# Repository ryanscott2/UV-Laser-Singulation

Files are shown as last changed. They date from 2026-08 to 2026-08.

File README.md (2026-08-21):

# UV Laser Singulation

Geometry preparation, stage control, and WinLase automation for four-field
singulation of a 100 mm silicon wafer on a UV galvo system.

Singulation workflow

The laser field remains fixed. A Prior OptiScan III stage moves an edge-datum
wafer jig through four taught positions (`P1`–`P4`), while each DXF is translated
so its field center is at the drawing origin. The result is a repeatable pipeline
from wafer-scale cut geometry to four field-centered WinLase jobs.

> [!CAUTION]
> This repository contains machine-specific geometry, calibration assumptions,
> motion limits, and laser-profile gates. It is not a transferable process recipe.
> UV radiation is invisible; use wavelength- and power-rated eyewear, the
> facility enclosure and interlocks, appropriate extraction for silicon debris,
> and the hardware emergency stop. Prove motion, placement, focus, and process
> settings on sacrificial material before an armed run.

## What the repository does

1. Generates or accepts wafer-centered DXF/GDS/OAS cut geometry.
2. Optionally separates a combined cut layer into horizontal and vertical passes.
3. Clips the design into four station jobs, translates each job to field origin,
   and writes manifests and build logs.
4. Reconstructs the masters from the emitted jobs and checks field placement.
5. Builds one WinLase job per station and runs the `P1 -> P2 -> P3 -> P4`
   stage/mark sequence.
6. Provides Fusion generators and exports for the current edge-datum wafer jig.

### Current geometry defaults

| Setting | Value |
| --- | ---: |
| Wafer | 100 mm |
| Qualified galvo field | 54 × 54 mm |
| Usable central field | 60 × 60 mm |
| Field centers in wafer coordinates | X,Y = ±25.4 mm |
| Split mode | `partition` |
| Total stitch overlap | 400 µm |
| Maximum cut-path width | 50 µm |
| Global placement offset | 0 µm, X and Y |

The stitch and field settings above are the defaults in
[`slicing/split_klayout.py`](slicing/split_klayout.py). They can be overridden by
the build tools, and every emitted set records the effective values.

## Requirements

| Environment | Requirements |
| --- | --- |
| Design/prep PC | Python 3.11+ and `klayout`; `PySide6` for the desktop slicer |
| Laser PC | Windows, Python 3.8+, WinLase Professional, `pywin32`, and either `pyserial` or the pywin32 serial backend |
| Jig regeneration | Autodesk Fusion with its Python API |

Install the prep dependencies:

```bash
pip install klayout PySide6
```

The command-line builders and validators need only `klayout`.

## Quick start: prepare and validate a set

From the repository root:

```bash
python slicing/build_pin_grid_set.py
python slicing/validate_pin_grid_set.py
```

The default build consumes the paired masters in
`dxf/100mm_10x30mm_Masters/` and writes a four-station set under
`output/DXFs/`. Each station folder contains one DXF per pass angle; the set
also contains a position manifest, split logs, and validation output.

For a design whose cut orientations share one layer:

```bash
python slicing/build_pin_grid_set.py \
  --combined wafer.gds \
  --cut-layer 7 \
  --edge-bead 2
```

Useful build controls include `--rotation`, `--jig-flat`, `--cut-width`,
`--width-mode`, `--stitch`, per-station `--offset`, independent X/Y window
centers, and `--clip-mode`. See the complete interface with:

```bash
python slicing/build_pin_grid_set.py --help
```

### Interactive slicer

```bash
python slicing/slicer_app.py
```

The PySide6/QML app previews the wafer, source layers, four-window or center-pass
clipping, cut width, offsets, and edge bead before writing the set. The same
workflow is available from the CLI wrapper:

```bash
python slicing/run_splitter.py --input wafer.dxf --list-layers
```

## Run on the laser PC

Transfer the validated set to the offline machine, then work through dry-run and
pre-flight modes before arming:

```bash
# Parse the set without WinLase, then verify the first job in memory.
python laser-pc/winlase_build_jobs.py output/DXFs/<set> --dry-run
python laser-pc/winlase_build_jobs.py output/DXFs/<set> --verify

# Build all four .wlj files. Close the WinLase GUI first.
python laser-pc/winlase_build_jobs.py output/DXFs/<set>

# Teach P1-P4 once for the current jig/datum, then inspect the run plan.
python laser-pc/optiscan.py jog
python laser-pc/dice_wafer.py output/DXFs/<set> --list

# Real stage motion, simulated marking.
python laser-pc/dice_wafer.py output/DXFs/<set>

# Live laser run.
python laser-pc/dice_wafer.py output/DXFs/<set> --arm
```

`dice_wafer.py` defaults to simulated marking but still moves the real stage. An
armed run adds typed confirmation and a countdown, checks all taught positions
against the current asymmetric stage envelope, verifies the laser profile before
any motion and again at mark time, and supports controlled stop flags. A controlled
stop is not an emergency stop.

The current job builder writes a 100 mm/s mark speed and requires the configured
WinLase profile to read back at 100% power and 30 kHz. The default run count is 175
passes unless overridden by `laser-pc/dice_passes.csv` or `--passes`. These are
rig-specific values recorded by the code, not recommendations for another laser.

For the Tk launcher, double-click [`laser-pc/run_ui.bat`](laser-pc/run_ui.bat).
Detailed machine setup and failure handling are in
[`laser-pc/WINLASE_AUTOMATION_README.md`](laser-pc/WINLASE_AUTOMATION_README.md).

## Coordinate contract

- Source geometry is wafer-centered.
- `P1`–`P4` identify stage/jig stations, not wafer quadrants.
- Each output is translated so its laser-field center lands at `(0, 0)`.
- WinLase auto-centering and fit-to-field scaling must remain off.
- The current edge-datum jig stays seated; the stage performs the indexing.
- Coarse placement lives in the taught stage positions. Splitter global and
  per-station offsets default to zero.

The validator translates every station job back into wafer coordinates, unions the
result, and requires zero XOR area against the source master. It also checks that
the emitted geometry fits the usable field around the origin and exits non-zero on
failure.

## Repository layout

| Path | Purpose |
| --- | --- |
| [`slicing/`](slicing) | KLayout generators, splitters, validators, CLI tools, and PySide6/QML preview |
| [`laser-pc/`](laser-pc) | OptiScan driver, WinLase job builder, sequenced dicer, and Tk launcher |
| [`fusion/`](fusion) | Edge-datum jig generators plus CAD/STL exports |
| [`dxf/`](dxf) | Source drawings and generated wafer masters |
| [`output/`](output) | Generated and validated job sets |
| [`docs/figures/`](docs/figures) | Documentation figures |

## Documentation

- [`DOCUMENTATION.md`](DOCUMENTATION.md) — coordinate frames, labeling,
  splitter guarantees, import settings, and jig details
- [`OPERATING_PROCEDURE.md`](OPERATING_PROCEDURE.md) — operator sequence
- [`CALIBRATION_AND_SLIDING_NEST_NOTES.md`](CALIBRATION_AND_SLIDING_NEST_NOTES.md)
  — measurement history and design decisions
- [`slicing/KLayoutFourWindowSplitter_README.md`](slicing/KLayoutFourWindowSplitter_README.md)
  — splitter configuration and output contract
- [`slicing/CenterPassWorkflow_README.md`](slicing/CenterPassWorkflow_README.md)
  — centered scoring workflow

## License

No license is granted. The repository is published for reference; all rights are
reserved.

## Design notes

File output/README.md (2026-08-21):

# Generated laser job sets

Each folder under `DXFs/` is one complete, validated set of exposure files. The
**current** sets are the dated N-angle sets under `DXFs/` — each station folder holds
one DXF per pass angle (e.g. `+45.0.dxf`), not a fixed Horizontal/Vertical pair —
including `082126_AlignmentTest_v1` through `_v3`.

The table below is **archived history**: these fixed-orientation sets predate the
N-angle pipeline. They are kept because the calibration history in
[CALIBRATION_AND_SLIDING_NEST_NOTES.md](../CALIBRATION_AND_SLIDING_NEST_NOTES.md)
refers to what they actually produced on the machine.

| Set (archived) | Jig | Field | Status |
| --- | --- | --- | --- |
| [080826_FourPosDicer_PinGrid54mm](DXFs/080826_FourPosDicer_PinGrid54mm) | eight-pin grid | `54 mm` | superseded by the N-angle sets |
| [080726_FourPosDicer_PinGrid52mm](DXFs/080726_FourPosDicer_PinGrid52mm) | eight-pin grid | `52 mm` | superseded |
| [080726_FourPosDicer_OriginLocked](DXFs/080726_FourPosDicer_OriginLocked) | original printed four-position | `60 mm` | superseded |
| [080726_FourPosDicer](DXFs/080726_FourPosDicer) | original printed four-position | `60 mm` | superseded, failed on the machine |

## Which labeling each set uses

The current set labels folders by **jig station**, numbered clockwise from the
table's top-left: `P1` is the top-left jig position, which exposes the wafer's
bottom-right quadrant (`P2` top-right, `P3` bottom-right, `P4` bottom-left). See the
[coordinate convention](../CALIBRATION_AND_SLIDING_NEST_NOTES.md#coordinate-convention).

Both old-jig sets predate that change and label folders by **exposed wafer
quadrant**, where `DXF11` means the wafer's top-left. They were deliberately not
renumbered, because the recorded seam measurements name those folders. Converting
between the schemes swaps `11` and `22` and leaves `12` and `21` alone.

## Why the failed set is still here

`080726_FourPosDicer` is the first full-wafer run. Its bottom-right horizontal
pass landed about `8 mm` low. The splitter math was correct: the cause was
per-file automatic centering during laser import, because that set has cutting
geometry on layer `0` and nothing else, so every file had a different content
bounding box.

`080726_FourPosDicer_OriginLocked` is the same geometry re-emitted with four
`50 um` registration anchors on `REGISTRATION_DO_NOT_EXPOSE`, which force an
identical bounding box in every file so an auto-centering importer cannot displace
one job.

The current pin-grid set drops the anchors entirely: it is exposed with the laser's
automatic centering turned **off**, so each job lands at its true coordinates (the
DXF origin on the field center), verified by the field-placement self-test in the
validator. Never use fit-to-field scaling.

## Regenerating

Only the current set is reproducible from this repository:

```bash
python slicing/build_pin_grid_set.py
python slicing/validate_pin_grid_set.py
```

The two old-jig sets came from a `split_klayout_four_windows_old_jig_test.py`
profile carrying window-pattern offsets for a jig that no longer exists. That file
was removed on 2026-08-08; recover it from git history if these ever need
rebuilding.

There are no rendered previews here. The earlier set was removed on 2026-08-08: it
showed the superseded 60 mm field and named its panels by the pre-relabel scheme,
so `DXF11` in those images meant what is now `P3`. The figures under
[docs/figures](../docs/figures) are generated from the current geometry instead.

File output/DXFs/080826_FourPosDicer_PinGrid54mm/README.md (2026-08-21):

# 100 mm wafer, 10 x 30 mm dice - 54 mm pin-grid production set

Current production set. Built and validated with:

```bash
python slicing/build_pin_grid_set.py
```

```bash
python slicing/validate_pin_grid_set.py
```

## Optical and stitch geometry

- Declared exposure window: `54.000 x 54.000 mm`. This is what the DXF header
  declares and where the registration anchors sit.
- Window actually occupied by each job: `51.000 mm`, being its own half of the
  `50.800 mm` pitch plus the stitch. It is centred in the 54 mm field, so there is
  `1.500 mm` of clear field on every side.
- Field centers on wafer: `X,Y = +/-25.400 mm`.
- Physical move between neighbouring stations: `50.800 mm`, two 1 inch grid spaces.
- Stitch overlap: `0.200 mm` total, so each job reaches `0.100 mm` past the nominal
  `X=0` and `Y=0` seams. That covers the `75-100 um` seam mismatch recorded in the
  calibration notes.
- Margin from the 54 mm window to every edge of the `60 mm` usable field: `3 mm`
  (the galvo's full `78.485 mm` field is weaker at the edges, so only the central
  60 mm is used).
- The stitch can be raised to `3.200 mm` before a window would exceed the declared
  field; the splitter refuses anything larger.
- All cutting geometry is on DXF layer `0`.
- Every file declares `$EXTMIN`/`$EXTMAX` at `+/-27.000 mm` and carries four
  `50 um` anchors on `REGISTRATION_DO_NOT_EXPOSE` with the same bounds.

Set `REGISTRATION_DO_NOT_EXPOSE` to no marking / zero power. Never expose that
layer and never use fit-to-field scaling.

## Wafer and cut geometry

- Wafer diameter: `100.000 mm`.
- Edge bead/exclusion: `2.000 mm`, from the single `EDGE_BEAD_MM` variable in
  `python/generate_100mm_10x30mm_masters.py`.
- Dice pitch: `10.000 mm` in X and `30.000 mm` in Y.
- Cut width: `50 um`.
- Alignment marker: centered 2.5 mm plus with 50 um arms. Wafer origin sits inside
  all four clip boxes, so every `Horizontal.dxf` carries the fragment of the plus
  that falls in its own box; the four fragments reassemble into the whole marker.

## Double exposure

Measured on this set:

| source | area at 2x dose | share of exposed area |
| --- | ---: | ---: |
| grid crossings, `Horizontal.dxf` meeting `Vertical.dxf` | `0.0700 mm2` in 28 spots | `0.14%` |
| seam overlap between neighbouring jobs | `0.4225 mm2` | `0.86%` |
| total | `0.4925 mm2` of `49.1333 mm2` | `1.00%` |

Acceptable here because the wafer is scored partway through rather than cut, and
the seam overlap is the deliberate stitch.

## Folder and pin mapping

Grid columns count from table left and rows from table front, starting at zero.

Folder labels name the **jig station**, read like a matrix: first digit is the row
from the table rear (`1` = top/rear, `2` = bottom/front), second is the column from
the table left (`1` = left, `2` = right). Indexing the jig moves the wafer, not the
laser, so each station exposes the diagonally opposite wafer quadrant.

Four locating pins per station, on the corners of a 4 x 4 grid-space square.

| Folder | Jig station | Exposure center | Exposed area | Engraved hole | Pin columns/rows |
| --- | --- | ---: | --- | --- | --- |
| `DXF11` | top-left | `(+25.4,-25.4) mm` | bottom-right | `C4 R3` | columns `0,4`; rows `3,7` |
| `DXF12` | top-right | `(-25.4,-25.4) mm` | bottom-left | `C6 R3` | columns `2,6`; rows `3,7` |
| `DXF21` | bottom-left | `(+25.4,+25.4) mm` | top-right | `C4 R1` | columns `0,4`; rows `1,5` |
| `DXF22` | bottom-right | `(-25.4,+25.4) mm` | top-left | `C6 R1` | columns `2,6`; rows `1,5` |

The engraved hole is the outer front-right pin, the single coordinate the jig plate
engraves for that station. Seating it fixes the other three.

Each folder contains `Horizontal.dxf` and `Vertical.dxf`. Keep the jig and wafer
stationary between those two files.

## What changed from the 52 mm set

`080726_FourPosDicer_PinGrid52mm` used a 52 mm field with a `1.200 mm` stitch, and
its window size was pinned to the field. The window size is now derived from the
pitch and the stitch alone, so the field is free to be larger than the window:

- field `52 -> 54 mm`, anchors and declared extents `+/-26 -> +/-27 mm`
- stitch `1.200 -> 0.200 mm`, so double-exposed area drops from `1.3925` to
  `0.4925 mm2`
- `CLIP_MODE` now has a real effect. At the old settings `partition` and
  `full_window` produced identical boxes; with a 54 mm field, `full_window` would
  overlap neighbours by `3.200 mm` and expose that whole band twice.

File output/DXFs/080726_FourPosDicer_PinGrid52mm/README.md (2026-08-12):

# 100 mm wafer, 10 x 30 mm dice - 52 mm pin-grid production set

> **Superseded on 2026-08-08** by
> [080826_FourPosDicer_PinGrid54mm](../080826_FourPosDicer_PinGrid54mm), which
> uses a 54 mm declared field and a 0.200 mm stitch instead of 52 mm and
> 1.200 mm. It also predates the removal of the inner four jig pins. Kept for
> traceability; do not mix its files with the current set.

This set uses the eight-pin grid jig and the production
`split_klayout.py` profile.

## Optical and stitch geometry

- Exposure/file bounds: `52.000 x 52.000 mm`.
- Field centers on wafer: `X,Y=+/-25.400 mm`.
- Physical move between neighboring positions: `50.800 mm` (two 1 inch grid
  spaces).
- Total field overlap: `1.200 mm`.
- Partition stitch overlap: `1.200 mm`, extending each job `0.600 mm` across
  the nominal X=0 and Y=0 seams.
- Margin from the 52 mm exposure to every edge of the `60 mm` usable field: `4 mm`
  (the galvo's full `78.485 mm` field is weaker at the edges, so only the central
  60 mm is used).
- All cutting geometry is on DXF layer `0`.
- Every file has four bounding anchors on `REGISTRATION_DO_NOT_EXPOSE`, fixing
  its content bounds at exactly `(-26,-26) to (+26,+26) mm`.

Set `REGISTRATION_DO_NOT_EXPOSE` to no marking / zero power. Never expose that
layer and never use fit-to-field scaling.

## Wafer and cut geometry

- Wafer diameter: `100.000 mm`.
- Edge bead/exclusion: `2.000 mm`, controlled by the single `EDGE_BEAD_MM`
  variable in `generate_100mm_10x30mm_masters.py`.
- Dice pitch: `10.000 mm` in X and `30.000 mm` in Y.
- Cut width: `50 um`.
- Alignment marker: centered 2.5 mm plus with 50 um arms. Because the `1.200 mm`
  stitch overlap puts wafer origin inside all four clip boxes, every
  `Horizontal.dxf` carries the fragment of the plus that falls in its own box;
  the four fragments reassemble into the whole marker.

## Folder and pin mapping

Grid columns count from table left and rows from table front, starting at zero.

Folder labels name the **jig station**, read like a matrix: the first digit is
the row from the table rear (`1` = top/rear, `2` = bottom/front) and the second
is the column from the table left (`1` = left, `2` = right). Indexing the jig
moves the wafer, not the laser, so each station exposes the diagonally opposite
wafer quadrant.

| Folder | Jig station | Exposure center | Exposed area | Engraved hole | Outer pins | Inner pins |
| --- | --- | ---: | --- | --- | --- | --- |
| `DXF11` | top-left | `(+25.4,-25.4) mm` | bottom-right | `C4 R3` | columns `0,4`; rows `3,7` | columns `1,3`; rows `4,6` |
| `DXF12` | top-right | `(-25.4,-25.4) mm` | bottom-left | `C6 R3` | columns `2,6`; rows `3,7` | columns `3,5`; rows `4,6` |
| `DXF21` | bottom-left | `(+25.4,+25.4) mm` | top-right | `C4 R1` | columns `0,4`; rows `1,5` | columns `1,3`; rows `2,4` |
| `DXF22` | bottom-right | `(-25.4,+25.4) mm` | top-left | `C6 R1` | columns `2,6`; rows `1,5` | columns `3,5`; rows `2,4` |

The engraved hole is the outer front-right pin, the single coordinate the jig
plate engraves for that station. Seating it fixes the other seven pins.

Each folder contains `Horizontal.dxf` and `Vertical.dxf`. Keep the jig and wafer
stationary between those two files.

## Relabeled 2026-08-08

This set originally labeled folders by the exposed wafer quadrant (`DXF11` =
wafer left-top). Labels now name the jig station instead. Only labels changed:
every DXF is byte-identical to the file it replaced, and the swap was exactly
`DXF11` <-> `DXF22`, with `DXF12` and `DXF21` keeping both name and contents.

| Exposed area | Old folder | New folder |
| --- | --- | --- |
| right-bottom | `DXF22` | `DXF11` |
| left-bottom | `DXF12` | `DXF12` |
| right-top | `DXF21` | `DXF21` |
| left-top | `DXF11` | `DXF22` |

The archived old-jig sets `output/DXFs/080726_FourPosDicer` and
`080726_FourPosDicer_OriginLocked` were left on the superseded wafer-quadrant
labeling for traceability.

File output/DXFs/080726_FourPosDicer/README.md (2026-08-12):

# 100 mm wafer, 10 x 30 mm dice — old-jig test set

> **Superseded, and labeled the old way.** This set predates the 2026-08-08
> convention change. Folders here are named for the **exposed wafer quadrant**,
> so `DXF11` holds the wafer's top-left. Current sets name the **jig station**,
> where `DXF11` is the top-left jig position and holds the wafer's bottom-right.
> Converting swaps `11` and `22` and leaves `12` and `21` alone. Do not mix files
> from this set with a current one, and do not run it on the pin-grid jig.

> This is additionally the run that **failed on the machine**: it carries no
> registration anchors, so the laser importer auto-centered each file on its own
> content bounds and displaced the bottom-right horizontal pass by about `8 mm`.
> Kept only as the record of that failure.

This output was generated with `generate_100mm_10x30mm_masters.py` and split
twice with the since-removed `split_klayout_four_windows_old_jig_test.py`: once for the vertical
master and once for the horizontal master. The same splitter accepts DXF, GDS,
and OAS input through KLayout.

## Folder coordinates

The two digits in `DXFxy` identify the exposed wafer area:

- X1 = wafer left; X2 = wafer right.
- Y1 = wafer rear/top; Y2 = wafer front/bottom.

| Folder | Wafer area | Physical field center in wafer coordinates |
| --- | --- | ---: |
| `DXF11` | left, rear/top | `(-28.982, +26.678) mm` |
| `DXF12` | left, front/bottom | `(-28.982, -23.322) mm` |
| `DXF21` | right, rear/top | `(+21.018, +26.678) mm` |
| `DXF22` | right, front/bottom | `(+21.018, -23.322) mm` |

Each folder contains exactly `Horizontal.dxf` and `Vertical.dxf`. Run both at
that jig position without moving the jig or wafer between files.

## Geometry

- Nominal wafer: 100 mm, primary flat forward and secondary flat left.
- Dice pitch: 10 mm in X and 30 mm in Y.
- Vertical cut centers: `+/-5, +/-15, +/-25, +/-35, +/-45 mm`.
- Horizontal cut centers: `+/-15, +/-45 mm`.
- Cut-feature width: 50 um.
- Protected edge: true 2 mm inward offset from the circular edge and both flats.
- Alignment marker: one centered plus, 2.5 mm long with 50 um arms, included
  only in `DXF22/Horizontal.dxf` by the non-overlapping partition.
- All output geometry is on literal DXF layer `0` with millimeter drawing units.

This set is compensated for the original printed four-position jig using the
window-pattern offset `X=-3.982 mm`, `Y=+1.678 mm`. It keeps each job inside the
centered 60 mm optical area, which fills the 60 mm usable field (the galvo's full
78.485 mm field is weaker at the edges, so only the central 60 mm is used). Do not use these files with the corrected jig.

Use a low-power sacrificial-wafer pass first and verify both the marker and a
few grid intersections before running the full dicing recipe.

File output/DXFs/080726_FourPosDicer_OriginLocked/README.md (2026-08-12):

# 100 mm wafer, 10 x 30 mm dice — old-jig test set

> **Superseded, and labeled the old way.** This set predates the 2026-08-08
> convention change. Folders here are named for the **exposed wafer quadrant**,
> so `DXF11` holds the wafer's top-left. Current sets name the **jig station**,
> where `DXF11` is the top-left jig position and holds the wafer's bottom-right.
> Converting swaps `11` and `22` and leaves `12` and `21` alone. Do not mix files
> from this set with a current one, and do not run it on the pin-grid jig.

This output was generated with `generate_100mm_10x30mm_masters.py` and split
twice with the since-removed `split_klayout_four_windows_old_jig_test.py`: once for the vertical
master and once for the horizontal master. The same splitter accepts DXF, GDS,
and OAS input through KLayout.

## Folder coordinates

The two digits in `DXFxy` identify the exposed wafer area:

- X1 = wafer left; X2 = wafer right.
- Y1 = wafer rear/top; Y2 = wafer front/bottom.

| Folder | Wafer area | Physical field center in wafer coordinates |
| --- | --- | ---: |
| `DXF11` | left, rear/top | `(-28.982, +26.678) mm` |
| `DXF12` | left, front/bottom | `(-28.982, -23.322) mm` |
| `DXF21` | right, rear/top | `(+21.018, +26.678) mm` |
| `DXF22` | right, front/bottom | `(+21.018, -23.322) mm` |

Each folder contains exactly `Horizontal.dxf` and `Vertical.dxf`. Run both at
that jig position without moving the jig or wafer between files.

## Geometry

- Nominal wafer: 100 mm, primary flat forward and secondary flat left.
- Dice pitch: 10 mm in X and 30 mm in Y.
- Vertical cut centers: `+/-5, +/-15, +/-25, +/-35, +/-45 mm`.
- Horizontal cut centers: `+/-15, +/-45 mm`.
- Cut-feature width: 50 um.
- Protected edge: true 2 mm inward offset from the circular edge and both flats.
- Alignment marker: one centered plus, 2.5 mm long with 50 um arms, included
  only in `DXF22/Horizontal.dxf` by the non-overlapping partition.
- All cutting geometry is on literal DXF layer `0` with millimeter drawing units.
- Four 50 um registration anchors are on `REGISTRATION_DO_NOT_EXPOSE`. They
  force every file to have the identical `(-30,-30) to (+30,+30) mm` bounding
  box and prevent the DXF22 alignment marker from changing automatic placement.

## Critical laser-import setting

Set `REGISTRATION_DO_NOT_EXPOSE` to no marking / zero power before running any
file. Never expose that layer. Layer `0` is the only cutting layer.

The registration layer makes per-file automatic centering geometrically stable,
but importing at the original drawing origin `(0,0)` remains preferred. Do not
use a fit-to-field operation that scales the drawing.

This set is compensated for the original printed four-position jig using the
window-pattern offset `X=-3.982 mm`, `Y=+1.678 mm`. It keeps each job inside the
centered 60 mm optical area, which fills the 60 mm usable field (the galvo's full
78.485 mm field is weaker at the edges, so only the central 60 mm is used). Do not use these files with the corrected jig.

Use a low-power sacrificial-wafer pass first and verify both the marker and a
few grid intersections before running the full dicing recipe.

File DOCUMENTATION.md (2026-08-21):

# Documentation

How the toolchain fits together, what the labels mean, and what the laser must be
told before a file is exposed. For the measurement history and why the design
ended up this way, see
[CALIBRATION_AND_SLIDING_NEST_NOTES.md](CALIBRATION_AND_SLIDING_NEST_NOTES.md).

## Contents

- [Scope and safety](#scope-and-safety)
- [Requirements](#requirements)
- [The labeling convention](#the-labeling-convention)
- [Pipeline](#pipeline)
- [Slicing an arbitrary pattern](#slicing-an-arbitrary-pattern)
- [Double exposure](#double-exposure)
- [Laser import settings](#laser-import-settings)
- [Jigs and printing](#jigs-and-printing)
- [Running the KLayout macros directly](#running-the-klayout-macros-directly)
- [Reference](#reference)

## Scope and safety

### What this repository is

Geometry generation and the fixtures that position a wafer. It produces DXF files
whose coordinates are correct with respect to one measured machine, and STLs for
jigs that index that wafer on a 1 inch table grid.

### What it is not

It specifies **no laser system and no process parameters**: no make or model, no
wavelength, no average or peak power, no laser class, no pulse energy, repetition
rate, scan speed, pass count, focus height, or assist gas. Nothing here has been
validated as a process. The only exposure statement in the whole repository is
geometric: cut features are `50 um` wide.

Consequently:

- **Laser eyewear must match your actual wavelength and power.** Generic safety
  glasses are not laser eyewear. UV is invisible, so there is no blink reflex to
  rely on. Work inside your facility's own laser safety controls, enclosure, and
  interlocks, under whatever authority governs that laser.
- **Silicon debris is a real hazard.** Laser-cutting silicon generates respirable
  particulate; fracturing a scored wafer throws sharp fragments. Use extraction
  appropriate to the material and contain the break.
- **"Low power" is deliberately undefined here** because it depends entirely on a
  laser this repository knows nothing about. Establish it empirically on
  sacrificial material, starting below anything you expect to mark.
- **The fracture workflow is an experiment, not a recipe.** Whether a scored wafer
  breaks cleanly depends on score depth, crystal orientation, thickness, coatings,
  and edge defects. Prove it on sacrificial wafers before trusting real material.

### Calibration is machine-specific

`LASER_ZERO = (96.190, 109.350) mm`, the nest offsets, and the field size were
measured by hand on one table with one printed jig, and are treated throughout as
authoritative *for that setup only*. On any other machine they are simply wrong.
Re-measure your own zero before cutting anything you care about, and treat the
numbers here as a worked example of the method rather than values to copy.

The history in
[CALIBRATION_AND_SLIDING_NEST_NOTES.md](CALIBRATION_AND_SLIDING_NEST_NOTES.md)
records one calibration that was already wrong once: an edge-derived field center
of `(100.172, 107.672)` was superseded by a directly measured `(96.190, 109.350)`,
a `1.678 mm` correction in Y.

There is now only one splitter. The old-jig profile that carried a hardcoded
`(-3.982, +1.678) mm` compensation for the original printed jig was removed on
2026-08-08 along with the jig itself; it would have placed geometry wrong on the
current one. It remains in git history if the archived sets ever need rebuilding.

## Requirements

- Python 3.11+ and the standalone KLayout wheel, which is all `slicing/` needs.
  Developed against `klayout` 0.30.9.
- Optionally the KLayout application, to run the macros in `slicing/` from its GUI
  or headless executable instead.
- Autodesk Fusion, only to regenerate the jig CAD and STLs. The scripts in
  `fusion/` use the Fusion API and cannot run outside it.

### Dependency licensing

Worth knowing before choosing a license for this repository:

- **KLayout is GPL-3.0-or-later.** Every script in `slicing/` imports
  its API (`pya`, or `klayout.db` from the wheel); the `laser-pc/` app does not
  (it uses pyserial + pywin32). If you distribute this code
  under a license of your own, look at how that interacts with the GPL before
  assuming a permissive license is available to you.
- **The Autodesk Fusion API is proprietary.** The scripts in `fusion/` import
  `adsk.core` and `adsk.fusion`, which exist only inside Fusion and are governed by
  Autodesk's terms. The `.manifest` files and `.vscode/launch.json` in each jig
  folder are Autodesk-generated add-in scaffolding.

## The labeling convention

This is the thing most likely to cause an expensive mistake.

Folder and job labels name the **jig station**: P1-P4, numbered clockwise from the
table's top-left (P1 top-left, P2 top-right, P3 bottom-right, P4 bottom-left).

Indexing the jig moves the wafer, not the laser. Both axes therefore invert, and
each station exposes the **diagonally opposite** wafer quadrant:

| Folder | Jig station | Engraved hole | Exposure center | Exposes |
| --- | --- | --- | ---: | --- |
| `P1` | top-left | `C1 R4` | `(+25.4, -25.4) mm` | wafer bottom-right |
| `P2` | top-right | `C3 R4` | `(-25.4, -25.4) mm` | wafer bottom-left |
| `P3` | bottom-right | `C3 R2` | `(-25.4, +25.4) mm` | wafer top-left |
| `P4` | bottom-left | `C1 R2` | `(+25.4, +25.4) mm` | wafer top-right |

The top-left jig station exposes the wafer's bottom-right

The laser field is bolted to the table at laser zero. Only the wafer moves, so
sliding the jig left and rearward slides the exposed area right and forward. The
red circle is the one hole the plate engraves for this station.

Grid columns count from the table left and rows from the table front, both from
one. The engraved hole is the outer front-left pin, the one to the left of the
wafer's primary flat. The four-pin pattern is rigid, so seating that single pin
fixes the other three; it always sits two grid spaces left of and two spaces
forward of the pin-pattern center.

Verify all of it from the table geometry rather than trusting this table:

```bash
python slicing/pin_grid_layout.py
```

### The old scheme

Sets generated before 2026-08-08 label folders by **exposed wafer quadrant**,
where `DXF11` means the wafer's top-left. Converting between the schemes swaps
`11` and `22` and leaves `12` and `21` unchanged, name and contents both. Two of
four folders therefore look untouched while meaning something different, so
confirm against the jig station, never the digits alone.

The archived sets under `output/` were deliberately not renumbered, because the
recorded seam measurements name those folders.

## Pipeline

```
dxf/100mm_10x30mm_Masters/          slicing/generate_100mm_10x30mm_masters.py
  Horizontal_master.dxf                 50 um cuts on a 10 x 30 mm grid, clipped
  Vertical_master.dxf                   2 mm inside the edge and both flats
        |
        |  slicing/split_klayout.py
        |  driven by slicing/build_pin_grid_set.py
        v
output/DXFs/<set>/P1..P4/           four 51 mm windows in a 54 mm declared field,
  +0.0.dxf +90.0.dxf ...             one DXF per pass angle, named by the angle
                                     (legacy H/V = +0.0/+90.0), each centered on
                                     (0,0), 0.2 mm stitch overlap
```

Each pass angle is a separate file for the same jig position, named by its angle.
Run them all without moving the jig or the wafer between them.

### Clip, then translate

Clip in wafer coordinates, then translate so the field center is the origin

The splitter intersects the master with one clip box per station, then translates
the result by the negative of that station's field center. Every output therefore
sits centered on `(0, 0)`, which is what the laser expects: run with auto-centering
off, it places each job at its true coordinates, so the DXF origin lands on the
field center and the wafer is reproduced exactly.

### Partition mode and the seam

Partition mode: one owner per quadrant plus a deliberate overlap

`partition` mode, the default, gives each quadrant a single owner so geometry is
cut once rather than twice, then extends each job `0.600 mm` past `X=0` and `Y=0`
so neighbours meet instead of leaving a gap. The zoom shows the only region where
two jobs deliberately overlap.

`CLIP_MODE` matters at the production settings. `partition` gives each quadrant
one owner and adds the stitch, so a window is `51 mm`. `full_window` takes the whole
`54 mm` declared field instead, overlapping neighbours by `3.2 mm` and exposing that
entire band twice.

### Guarantees the splitter enforces

Three checks run on every build, so a square origin-centred window does not
depend on anyone remembering the relationship between the settings:

1. **The window fits the field.** A partition window spans
   `2 x WINDOW_CENTER + STITCH_OVERLAP_UM`, set by the jig's two-grid-space move
   and the stitch. The declared field must be at least that wide or geometry would
   fall outside the window the laser is told to expose; at `54 mm` the stitch may go
   up to `3.2 mm`. Both window centers must also match.
2. **Every window is square.** Each clip box is checked to be square, of the
   expected size, symmetric about its own field center after translation, and
   inside the declared field.
3. **Nothing is silently discarded.** Geometry outside all four windows is
   measured before clipping and stops the run, reporting the lost area and its
   bounds. A pattern reaching `+/-70 mm` loses `148.8 mm2`, `26.8%` of the cut
   geometry, and without this check produced four healthy-looking square files
   and a zero exit code. Pass `-rd allow_geometry_outside_fields=1` when clipping
   the pattern away really is intended.

The split log records all three, including the source and dropped areas.

### Field and stitch geometry

- Declared field: `54.000 x 54.000 mm`, the qualified field the windows sit inside.
- Window occupied per job: `51.000 mm`, its own half of the pitch plus the stitch,
  centred in the field with `1.500 mm` clear on every side.
- Field centers on the wafer: `X,Y = +/-25.400 mm`.
- Physical move between neighboring stations: `50.800 mm`, two 1 inch grid spaces.
- Total stitch overlap: `0.200 mm`, so each job extends `0.100 mm` across the
  nominal `X=0` and `Y=0` seams. That covers the `75-100 um` seam mismatch the
  calibration notes measured.
- Margin from the 54 mm window to every edge of the `60 mm` usable field: `3 mm`.
  The galvo's full field is about `78.485 mm`, but it weakens toward the edges, so
  only the central `60 mm` is used.
- Dice pitch `10.000 mm` in X, `30.000 mm` in Y. Cut width `50 um`.
- Edge bead / exclusion `2.000 mm`, applied inward from the circular edge and
  both flats, from the single `EDGE_BEAD_MM` variable in the master generator.

### Validation

`slicing/validate_pin_grid_set.py` runs two independent checks and exits non-zero if
either fails:

1. **Reconstruction.** Each tile is translated back by its own field center and
   unioned. The result must XOR to exactly zero area against the layer-0 master,
   proving no cut geometry was lost, duplicated, or shifted by the split.
2. **Field placement.** A self-test with the origin at the field center: every
   tile's layer-0 geometry must fit within `+/-30 mm` of the origin, the usable
   field half. It also reports how far a job would be misplaced if auto-centering
   were left on.

## Laser import settings

Layer `0` is the only cutting layer.

Placement relies on **true coordinates**. Run the laser (WinLase Pro) with
auto-centering **off**, so it places each job at its true coordinates and the DXF
origin lands on the field center. The splitter already writes every tile with its
field center at the DXF origin, so this reproduces the wafer exactly. This was
confirmed empirically on the machine with a placement probe.

**Turn auto-centering off. Never use fit-to-field scaling. Import at the drawing
origin.**

This is not theoretical. A full-wafer run displaced one horizontal pass by about
`8 mm` because the importer auto-centered each file on its content bounds, and one
file's bounds were skewed by the centered alignment marker. The splitter math was
correct; the placement was not. With cutting geometry alone, `DXF12` and `DXF22`
of that failed set have bounding-box centers `8.1125 mm` apart in Y, which is what
landed on the wafer. Placing each job at its true coordinates instead makes
per-file centering irrelevant.

## Jigs and printing

| Script | Jig |
| --- | --- |
| [`fusion/AlignerEdgePLA`](fusion/AlignerEdgePLA) / [`fusion/AlignerEdgeAL`](fusion/AlignerEdgeAL) | Current edge-datum wafer jig: PLA print and machined-aluminium spider. |

The edge-datum jig is a single plate located by an **L against the table's front-left corner** —
a left-edge datum bar (X + yaw) and a front-edge datum foot (Y), contacted by set screws
(aluminium) or small nubs (PLA); a rubber-band anchor on a press-fit rod preloads it up-and-right
into those datums. Unlike the retired pin-grid jig it does **not** move between table holes — it
stays pinned and the OptiScan stage indexes the wafer under the fixed field. The wafer nest center
sits at table `(92.45, 100.33) mm` (the `9.76 mm` forward shim is baked into `NEST_CENTER_Y`). Full
dimensions, tolerances, and the hole map are on the aluminium drawing,
[`edge_datum_wafer_jig_al_DRAWING.pdf`](fusion/AlignerEdgeAL/edge_datum_wafer_jig_al_DRAWING.pdf).

The earlier four-pin-grid and single-position jigs (`AlignerPLA` / `AlignerAL` / `AlignerSLA`,
`single_jig_wafer_indexer.scad`) were removed 2026-08-21 — see git history if you need them.

To regenerate a jig: open Fusion, press **Shift+S**, on the Scripts tab click
**+** and select the script's folder, then Run. Each script writes its `.f3d` and
`.step` beside itself and a high-quality binary `.stl` into
[`fusion/print-files`](fusion/print-files).

Print the PLA jig with the wafer nest upward (supports off the nest floor); machine the aluminium
spider from the laser/waterjet profile per its drawing. The committed STLs are **stale after the
9.76 mm shim change** — regenerate from the scripts before printing.

## Slicing an arbitrary pattern

The production path (`slicing/build_pin_grid_set.py`) is wired to the 100 mm masters.
To slice something else, pick which layer holds the cutlines and what width they
should be.

### One combined cut layer

The production build takes two pre-separated masters, one horizontal and one
vertical. When a source instead carries both orientations on a single layer — as
customer layouts often do, drawn as connected street networks or die-outline
frames — `build_pin_grid_set.py` can split it in one step:

```bash
python slicing/build_pin_grid_set.py --combined wafer.gds --cut-layer 7 --set output/DXFs/MySet
```

It reads the cut layer, decomposes it into axis-aligned rectangles, and sorts each
by its long axis into a horizontal pass and a vertical pass; crossing junctions
join both passes so no cut line is broken. The split is lossless — `H | V`
reconstructs the layer exactly — and it aborts if the layer is not purely
axis-aligned (author those cuts on two layers and use `--masters` instead).
`--cut-layer` takes a GDS number like `7` or `7/0`, and `--edge-bead <mm>` insets
the cuts from the wafer edge first. Validate the result with the `--master-stem`
the build prints.

One combined cut layer, split into horizontal and vertical passes

### Desktop window

```bash
python slicing/slicer_app.py
```

PySide6 + QML, using Qt's own `FluentWinUI3` style pinned to dark.

```bash
pip install PySide6
```

**On Windows, enable long paths first.** The PySide6 wheel's deepest file sits about
142 characters below `site-packages`, which overruns the legacy 260 character limit
on any interpreter whose `site-packages` path is already long — the Windows Store
Python's is 138. The install then fails partway and leaves a tree that looks
installed but has **no QML modules at all**, so every `import QtQuick.Controls`
fails with `plugin "qtquickcontrols2plugin" not found`. Fix it once, from an
administrator shell:

```bash
reg add "HKLM\SYSTEM\CurrentControlSet\Control\FileSystem" /v LongPathsEnabled /t REG_DWORD /d 1 /f
```

New processes pick it up; reinstall PySide6 afterwards with `--force-reinstall` if a
partial tree was already left behind.

If you would rather not touch the registry, a venv at a short path such as
`C:/Users/<you>/venvs/uvlaser` keeps every path inside the limit and works without
admin rights.

Choose a file and it reads the layers out of it, showing shape counts, drawn area,
and existing path widths for each. It preselects the layer with the most drawn area,
which is the cutline layer in every file this toolchain has seen, but any layer can
be chosen by name or by number.

Width has two modes. **Cap** narrows only paths wider than your value and leaves
thinner ones alone; **force** sets every path to exactly your value, widening as
well as narrowing. The window says so explicitly when the chosen layer holds filled
polygons, because those carry their size as geometry and no width setting can change
them — the generated 100 mm masters are polygons for exactly that reason.

The preview has two views. **Wafer** draws the source with the four windows over it,
the seam cross, the wafer outline, and the edge-bead ring when one is set, as a
guide. **Sliced jobs** draws
the four outputs as the laser will see them, each centred on its own origin. Both are
computed by calling the splitter's own clip and layer functions, so the preview cannot
drift from what a run writes.

**Alignment**, pinned at the bottom left, tunes placement without editing code: one
offset for all four jobs, and a per-station nudge on top of it. It moves the cut
geometry relative to the field center.

**Wafer edge bead**, entered in millimetres, insets the cut geometry from the wafer
edge before slicing — the same safe region the master generator uses — and the
dashed guide ring follows the value entered. `0` leaves the geometry untouched.

**Datasets** are named settings, kept in `slicing/.ui_datasets.json` as
`{name: {settings}}`. Save, reload and delete them from the header.

### Command line

The same options without the window:

```bash
python slicing/run_splitter.py --input wafer.dxf --list-layers
```

```bash
python slicing/run_splitter.py --input wafer.dxf --layer CUT --cut-width 40 --width-mode force --output jobs/
```

Add `--allow-outside`, `--global-x/--global-y`,
`--clip-mode`, `--stitch`, `--edge-bead`, or `--extension` as needed. This is also the supported way
to drive the splitter from plain Python, since the macro itself reads overrides from
`globals()` and parses no arguments of its own.

## Double exposure

Two places in the current recipe expose the same area twice. Measured on the
production set:

| source | area at 2x dose | share of exposed area |
| --- | ---: | ---: |
| grid crossings, where the `+0.0.dxf` pass meets the `+90.0.dxf` pass | `0.0700 mm2` in 28 spots of `50 x 50 um` | `0.14%` |
| seam overlap, where two neighbouring jobs both reach past `X=0` / `Y=0` | `0.4225 mm2` | `0.86%` |
| total | `0.4925 mm2` of `49.1333 mm2` | `1.00%` |

The **seam overlap is deliberate** — it is the `0.2 mm` stitch that stops a gap
appearing at the seam — and it is still the larger contributor. The **crossings are
incidental**: they land exactly on the corners of every die, which is where chipping
starts, so if corner quality matters they are worth removing.

Scoring partway through rather than cutting is what makes a small double-dosed band
acceptable. At the previous `1.2 mm` stitch the total was `1.3925 mm2`, `2.83%`.

Removing them needs no change to what gets cut. Emitting `Vertical - Horizontal`
instead of `Vertical` leaves the union bit-identical (verified: XOR area zero) while
dropping crossing overlap to zero, at the cost of `0.0700 mm2` less vertical
geometry. Not implemented; raise it if you want it.

## Running the KLayout macros directly

The KLayout macros in `slicing/` read their overrides out of `globals()`, which is
KLayout's `-rd` mechanism. They have no `argv` parsing, so plain
`python script.py` cannot be parameterized; that is what the wrapper scripts
(`run_splitter.py`, `build_pin_grid_set.py`) in `slicing/` are for.

From the repository root, with KLayout's headless executable:

```powershell
& "$env:APPDATA\KLayout\klayout_vo_app.exe" -zz -rx -r .\slicing\split_klayout.py -rd "input=.\dxf\100mm_10x30mm_Masters\100mm_wafer_10x30mm_Horizontal_master.dxf" -rd "output_dir=.\output\four_window_output"
```

Or from the KLayout GUI with **File > Run Script**, after editing `INPUT_FILE` and
`OUTPUT_DIR` at the top of the script.

## Provenance of the committed files

Not everything checked in is reproducible from the current scripts. What is what:

- `dxf/100mm_10x30mm_Masters/` is generated. Re-running
  `slicing/generate_100mm_10x30mm_masters.py` with
  `-rd output_dir=dxf/100mm_10x30mm_Masters` reproduces both DXFs byte-for-byte.
- `dxf/080526_HorizDicev2.dxf` and `dxf/080526_VertDicev2.dxf` are the earlier
  hand-drawn reference drawings the toolchain was first developed against. They are
  inputs, not generated, and no script produces them.
- `slicing/examples/` was produced by earlier revisions of the splitter and the
  center-pass script, at a 60 mm field with zero stitch overlap and an older
  manifest schema. It is illustrative output only: the current scripts will not
  reproduce those files, and their `validation_report.txt` metrics come from a
  checker that no longer exists in this repository. `slicing/validate_pin_grid_set.py`
  is the current one.

## Figures

Every figure on this page is generated, not drawn:

```bash
python slicing/make_figures.py
```

Cut geometry is read out of the master DXFs and station geometry comes from
`slicing/pin_grid_layout.py`. Regenerate after changing either of those and the
figures follow. Cut features are `50 um` wide on a `100 mm` wafer, so they are
stroked to stay visible; everything else is to scale except the seam zoom, which
is labelled as such.

## Reference

- [Four-window splitter](slicing/KLayoutFourWindowSplitter_README.md) — every setting and the full window mapping
- [Center-pass workflow](slicing/CenterPassWorkflow_README.md) — the single centered scoring job
- [Generated job sets](output/README.md) — what each set is and which labeling it uses
- [Wafer jig](fusion/AlignerEdgeAL/edge_datum_wafer_jig_al_DRAWING.pdf) — the current edge-datum jig: dimensions, tolerances, hole map (aluminium drawing; PLA + AL generator scripts under `fusion/AlignerEdgePLA` / `fusion/AlignerEdgeAL`)

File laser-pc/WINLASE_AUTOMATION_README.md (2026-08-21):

# Auto-building WinLase jobs (`winlase_build_jobs.py`)

Turns a built pin-grid set into ready WinLase Pro jobs so you stop importing and
re-entering settings by hand for every pass. It makes **4 jobs per wafer** — one per
station (P1–P4), each holding every pass-angle DXF in that station's folder (named by
angle, e.g. `+45.0.dxf`), with the parallel-fill angle read from the filename; legacy
`Horizontal.dxf` / `Vertical.dxf` are a fallback mapping to 0° / 90°. Each is positioned
at true field coordinates, with 0.01 mm fill spacing, 1 pass, mark-fill on / outline
off. Output lands in `<set>/WinLaseJobs/`.

It drives WinLase Professional's COM automation server (`Winlase.Automate`,
`IAutomate` interface) per the *WinLase Automation Server Reference Manual* (Lanmark
Controls). It only **builds and saves** `.wlj` files — it never marks.

## Prerequisites (on the laser PC)
- WinLase Professional + its dongle + a scan card, with a lens cal loaded.
- Python + `pywin32`:  `pip install pywin32`
- **Close the WinLase GUI first** — the GUI and the automation server can't hold the
  marker library at the same time.

## Run it
Off-machine, confirm the plan (no WinLase needed):
```bash
python laser-pc/winlase_build_jobs.py output/DXFs/082126_AlignmentTest_v1 --dry-run
```
On the laser PC, verify placement on one job without saving, then build all four:
```bash
python laser-pc/winlase_build_jobs.py output/DXFs/082126_AlignmentTest_v1 --verify
python laser-pc/winlase_build_jobs.py output/DXFs/082126_AlignmentTest_v1
```
Several wafers at once:
```bash
python laser-pc/winlase_build_jobs.py output/DXFs/082126_AlignmentTest_v1 output/DXFs/082126_AlignmentTest_v2 output/DXFs/082126_AlignmentTest_v3
```

`--verify` imports P1 in memory and reports each object's placement delta, a size
sanity check, and an out-of-bounds check. **No warnings ⇒ safe to run the full build.**

## Still done by hand (by design)
Per `OPERATING_PROCEDURE.md` §3, in the WinLase GUI once per job:
- **Job loop = 175×** — a run-time execution setting, not stored geometry.
- **Z / table height**, jig re-seat between stations, and the actual mark (P1→P2→P3→P4).

Mark **speed (400 mm/s)** and **laser power/frequency** are inherited from WinLase's
current **default profile**; the script prints that profile so you can confirm it and
deliberately does not write laser parameters. If the default speed isn't 400 mm/s, set
it once in the GUI's default profile (it's global, not per-file).

## If `--verify` shows warnings
- **Size mismatch** (imported bits ≠ expected) → the DXF import filter is scaling;
  tell me and I'll pin the import filter / add explicit scaling.
- **Out of bounds** → the lens field is smaller than the mark radius; check the loaded
  lens cal.
- **COM errors on the first call** → your `winlase.tlb` may flag an `[out]` parameter
  differently; the COM calls are all isolated in `WinLaseSession` for a quick fix.

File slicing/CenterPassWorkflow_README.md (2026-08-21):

# Center-pass KLayout job

This makes one centered laser-field job. The dedicated center-pass Fusion jig was
retired on 2026-08-11, and the four-pin-grid jig that replaced it was itself removed
2026-08-21. Seat the wafer in the current edge-datum jig
([`../fusion/AlignerEdgePLA`](../fusion/AlignerEdgePLA) / [`../fusion/AlignerEdgeAL`](../fusion/AlignerEdgeAL)),
whose nest is already centered on the field.

## Geometry assumption

`75 mm` is treated as the **scored diameter**, not radius. A standard 100 mm
wafer has a 50 mm radius, so a 75 mm score radius cannot fit on the wafer. The
default 75.000 mm score circle fits the galvo's 78.485 mm square max field but
exceeds the 60 mm qualified usable field, so it reaches into the weaker edge region.

## KLayout center-pass script

The center pass is `mode=center_pass` of `split_klayout.py`, so it
shares that file's `GLOBAL_X_OFFSET_UM` / `GLOBAL_Y_OFFSET_UM` with the
four-window split. Both are `0`: calibration lives in the taught stage stations and
the baked edge-jig forward shim, not in the DXF. Its center-pass settings there are:

```python
SCORE_DIAMETER_UM = 75_000.0
SCORE_SHAPE = "circle"      # `circle` or `square`
FULL_FIELD_SIZE_UM = 78_485.0
```

Native DXF/KLayout paths wider than `MAX_CUT_WIDTH_UM` are narrowed around their
existing centerlines before clipping. Closed filled contours are polygons rather
than paths and keep their drawn dimensions unless the width mode is `force`. The
supplied DXFs are read as 1 DXF unit = 1 mm; the generated DXF is also in
millimeters, on layer `0`.

Run it from the slicer UI (choose **Center pass**), from KLayout with
**File > Run Script**, or headlessly:

```powershell
klayout_app.exe -zz -rx -r split_klayout.py `
  -rd "mode=center_pass" `
  -rd "input=C:\path\to\wafer_cutlines.dxf" `
  -rd "output_dir=C:\path\to\center_output" `
  -rd "score_diameter_um=75000" -rd "score_shape=circle"
```

Or via the CLI wrapper: `python slicing/run_splitter.py --input wafer.dxf --mode
center-pass --score-diameter 75000`. The output is `<input_name>_center_pass.dxf`
plus a text log.

## Physical sequence

1. Seat the wafer in the current edge-datum jig (primary flat forward, seated against
   the front/left datums; see ../fusion/AlignerEdgePLA / ../fusion/AlignerEdgeAL).
2. Confirm the wafer is flat, clean, and fully seated before focusing.
3. Run a low-power alignment target first; placement calibration lives in the
   pin-grid jig / splitter offset, not here.
4. Run the centered DXF once without moving the jig or wafer.
5. Remove the wafer with the plate's pickup tab. Evaluate fracture behavior on a
   sacrificial wafer before relying on a scored break for finished material.

Wear eye protection and contain fragments when testing a scored break. Score
depth, crystal orientation, wafer thickness, coatings, and edge defects all
affect whether it breaks cleanly; the 75 mm diameter is a starting experiment,
not a guaranteed fracture recipe.

## Validation

Both supplied reference DXFs were processed and reopened with KLayout. The
generated geometry had zero XOR difference from the intended centered 75 mm
circular clip, and remained on layer `0`.

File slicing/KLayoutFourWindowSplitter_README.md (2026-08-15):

# Four-window KLayout cutline splitter

`split_klayout.py` reads wafer-centered cut geometry from layer 0
and writes laser-centered jobs. It supports DXF, GDS, and OAS input through
KLayout. DXF input and output use millimeters; configuration values use microns.

This is the single production splitter and carries the 54 mm pin-grid profile.
An identical copy previously existed as `split_klayout_four_windows_pin_grid.py`;
it has been removed, so edit this file only.

It runs in one of two modes (`-rd mode=...`). `four_windows` (default) is the
production four-station split documented below. `center_pass` instead clips one
centered score job (see [CenterPassWorkflow_README.md](CenterPassWorkflow_README.md));
both modes share the `GLOBAL_*_OFFSET_UM` calibration and every helper in the file.

## Important variables

Edit these near the top of the script:

- `INPUT_FILE`
- `OUTPUT_DIR`
- `GLOBAL_X_OFFSET_UM`
- `GLOBAL_Y_OFFSET_UM`
- `MAX_CUT_WIDTH_UM` (default `50.0`)
- `STITCH_OVERLAP_UM`
- `CLIP_MODE`
- `ALLOW_GEOMETRY_OUTSIDE_FIELDS` (default `False`)

Positive global X moves cut geometry right in every output. Positive global Y
moves it up. The global offsets do not alter the source file.

Native DXF/KLayout paths wider than `MAX_CUT_WIDTH_UM` are narrowed around
their existing centerlines before the four jobs are clipped. The default cap is
`50 um`; thinner paths are unchanged. Closed filled contours are polygons, not
paths, so their dimensions are preserved. The split log and manifest record how
many native paths were capped.

The default pin-grid `partition` mode uses `200 um` total stitch overlap: each
neighboring job extends `100 um` across X=0 and Y=0, which covers the 75-100 um
seam mismatch in the calibration notes.

`CLIP_MODE` matters at the production settings. `partition` gives each quadrant one
owner and adds the stitch, so a window is `2 x 25,400 + 200 = 51,000 um`.
`full_window` takes the whole `54,000 um` declared field instead, which overlaps
neighbours by `3,200 um` and exposes that entire band twice.

## Enforced window geometry

The window size is derived from the pitch and the stitch, not from the field, so
the declared field is free to be larger than the window. Every run checks:

1. The declared field must be at least as wide as a partition window,
   `2 * WINDOW_CENTER_UM + STITCH_OVERLAP_UM`, or geometry would fall outside the
   window the laser is told to expose. At a 54,000 um field the stitch may go up to
   `3,200 um`. Both window centers must also match, or the four windows are not a
   symmetric 2 x 2 tiling.
2. Each emitted window is asserted square, of the expected size, symmetric about
   its own field center once translated, and within the declared field.
3. Geometry outside all four windows is measured before clipping and stops the
   run, reporting the lost area and its bounds. Override with
   `-rd allow_geometry_outside_fields=1` when clipping it away is intended.

The split log and manifest record all three, plus any job that came out empty.

## Window mapping

Jobs are named for the **jig station** that produces them. P1-P4 name the jig
station, numbered clockwise from the table's top-left (P1 top-left, P2
top-right, P3 bottom-right, P4 bottom-left).

Indexing the jig moves the wafer, not the laser, so both axes invert and each
station exposes the diagonally opposite wafer quadrant:

| Job | Jig station | Window center in wafer coordinates | Owned quadrant |
| --- | --- | ---: | --- |
| `P1_jig_top_left` | top-left | +25,400 um X; -25,400 um Y | right / bottom |
| `P2_jig_top_right` | top-right | -25,400 um X; -25,400 um Y | left / bottom |
| `P3_jig_bottom_right` | bottom-right | -25,400 um X; +25,400 um Y | left / top |
| `P4_jig_bottom_left` | bottom-left | +25,400 um X; +25,400 um Y | right / top |

Each output is translated so its own laser-field center is `(0, 0)`. A manifest
CSV records the jig station, exposed wafer area, clip box, translation, polygon
count, and output bounding box for every job.

## Run from PowerShell

Use KLayout's headless executable:

```powershell
& "$env:APPDATA\KLayout\klayout_vo_app.exe" -zz -rx -r .\slicing\split_klayout.py -rd "input=.\dxf\100mm_10x30mm_Masters\100mm_wafer_10x30mm_Horizontal_master.dxf" -rd "output_dir=.\output\four_window_output" -rd "global_x_um=0" -rd "global_y_um=0" -rd "max_cut_width_um=50"
```

Run it from the repository root. The `-rd` values override the editable defaults
without modifying the script.

This script has no `argv` parsing of its own: overrides arrive through
`globals()`, which is KLayout's `-rd` mechanism. To drive it from plain Python
with the standalone `klayout` wheel, use the build tool, which injects those
same values and then assembles the labeled folder structure:

```bash
python slicing/build_pin_grid_set.py
```

## Generated 100 mm dicing masters

`generate_100mm_10x30mm_masters.py` uses one top-level edge-bead setting in
millimeters:

```python
EDGE_BEAD_MM = 2.000
```

The same value is applied inward from the circular edge, primary flat, and
secondary flat. It can also be overridden with `-rd edge_bead_mm=...`.

## Outputs

- Four files named `P1_jig_top_left` through `P4_jig_bottom_left`
- A `window_manifest.csv`
- A `split_log.txt`

DXF outputs contain closed `LWPOLYLINE` cut polygons on literal layer `0` and
retain the source convention of 1 drawing unit = 1 mm.

Jobs are placed by their true coordinates with the laser's auto-centering OFF,
so the DXF origin lands on the field center exactly as written. All cut geometry
lives on layer `0`; there are no registration anchors and no declared header
extents.

The production field is `54 x 54 mm` and each job occupies `51 x 51 mm` of it,
centred, leaving `1.5 mm` of clear field on every side. A centred 54 mm job retains
`3 mm` margin to every edge of the `60 mm` usable field.

## The removed original-jig profile

For the record, since the archived sets under `output/` were built with it.

The original printed four-position jig needed its own profile, because the directly
measured `(0, 0)` cross showed its four physical laser-window centers were the
nominal `+/-25 mm` grid shifted in wafer coordinates by `X = -3.982 mm` and
`Y = +1.678 mm`. That profile moved both the clipping windows and their output
translations by those amounts, on a 60 mm field.

It was deleted on 2026-08-08 along with the jig it compensated: with the pin-grid
jig those offsets are simply wrong, and a splitter that silently misplaces geometry
by 4 mm is not worth keeping on disk. Recover it from git history if the archived
sets ever need rebuilding.

It emitted the superseded `P1_right_top` .. `P4_left_bottom` names, keyed to the
exposed wafer quadrant rather than the jig station. Those names appear in the
archived old-jig build logs, whose delivered folders were renamed to `DXF11` ..
`DXF22` by hand at the time.

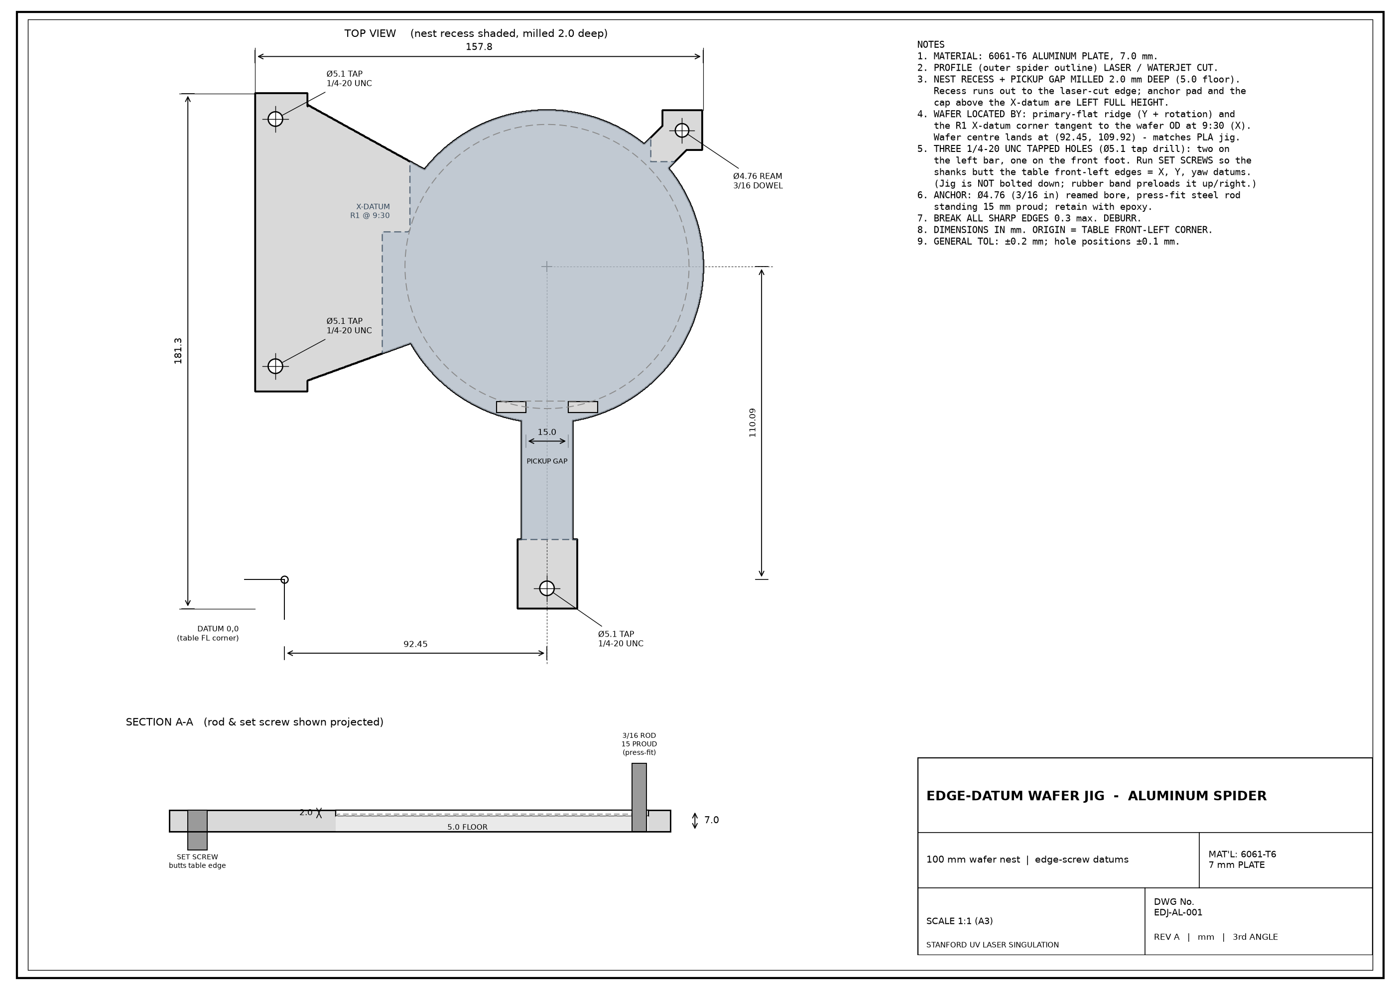
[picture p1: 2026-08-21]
fusion/AlignerEdgeAL/edge_datum_wafer_jig_al_DRAWING.png

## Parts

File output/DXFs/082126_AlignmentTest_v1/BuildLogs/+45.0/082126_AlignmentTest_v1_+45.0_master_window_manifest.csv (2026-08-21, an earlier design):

job | output_file | jig_station | exposed_wafer_area | field_center_x_wafer_um | field_center_y_wafer_um | clip_left_um | clip_bottom_um | clip_right_um | clip_top_um | output_translate_x_um | output_translate_y_um | max_cut_width_um | cut_width_mode | station_offset_x_um | station_offset_y_um | source_layer_selector | source_paths_capped | output_bbox_um | polygon_count | has_cut_geometry
P1_jig_top_left | 082126_AlignmentTest_v1_+45.0_master_P1_jig_top_left.dxf | top_left | bottom_right | 25400.0 | -18000.0 | -7600.0 | -51000.0 | 58400.0 | 15000.0 | -25400.0 | 18000.0 | 50.0 | cap | 0.0 | 0.0 | default (0/0 or a layer named '0') | 0 | 2866.594;-17373.017;9973.017;-10266.594 | 1 | True
P2_jig_top_right | 082126_AlignmentTest_v1_+45.0_master_P2_jig_top_right.dxf | top_right | bottom_left | -25400.0 | -18000.0 | -58400.0 | -51000.0 | 7600.0 | 15000.0 | 25400.0 | 18000.0 | 50.0 | cap | 0.0 | 0.0 | default (0/0 or a layer named '0') | 0 |  | 0 | False
P3_jig_bottom_right | 082126_AlignmentTest_v1_+45.0_master_P3_jig_bottom_right.dxf | bottom_right | top_left | -25400.0 | 18000.0 | -58400.0 | -15000.0 | 7600.0 | 51000.0 | 25400.0 | -18000.0 | 50.0 | cap | 0.0 | 0.0 | default (0/0 or a layer named '0') | 0 | -9973.017;10266.594;-2866.594;17373.017 | 1 | True
P4_jig_bottom_left | 082126_AlignmentTest_v1_+45.0_master_P4_jig_bottom_left.dxf | bottom_left | top_right | 25400.0 | 18000.0 | -7600.0 | -15000.0 | 58400.0 | 51000.0 | -25400.0 | -18000.0 | 50.0 | cap | 0.0 | 0.0 | default (0/0 or a layer named '0') | 0 |  | 0 | False

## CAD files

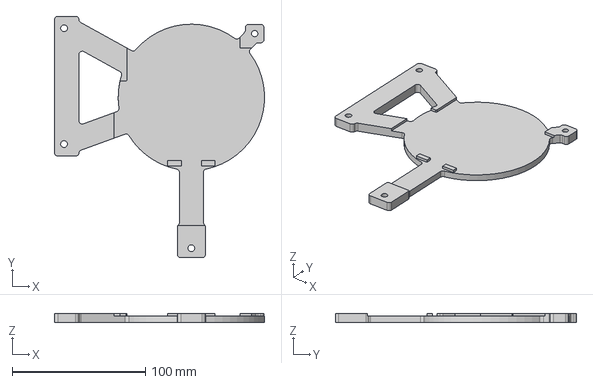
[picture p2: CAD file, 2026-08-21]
fusion/AlignerEdgeAL/edge_datum_wafer_jig_al.step
157.7 x 181.3 x 7.00 mm

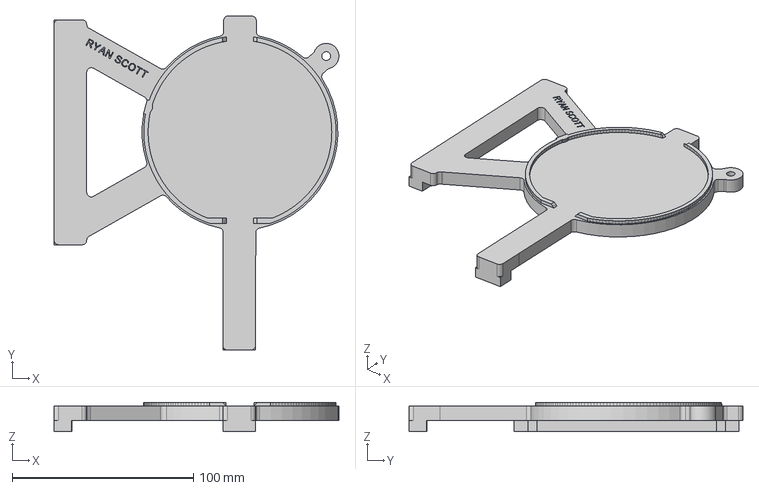
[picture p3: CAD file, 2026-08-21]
fusion/AlignerEdgePLA/edge_datum_wafer_jig.step
157.0 x 184.1 x 16.0 mm

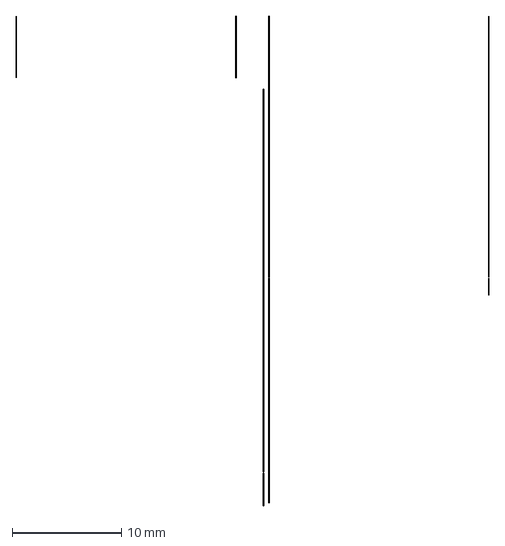
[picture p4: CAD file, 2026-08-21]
output/DXFs/081126_4Ford1MetaP100/P1/Vertical.dxf
43.3 x 44.8 mm

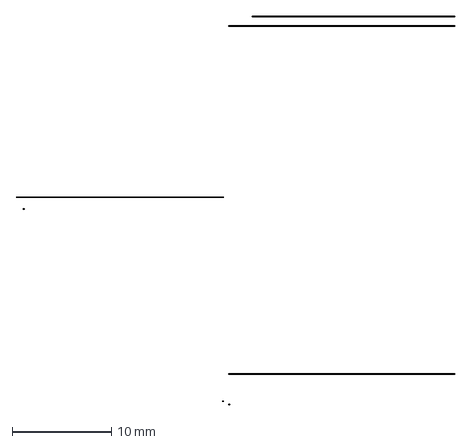
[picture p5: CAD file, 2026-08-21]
output/DXFs/081126_4Ford1MetaP100/P2/Horizontal.dxf
44.2 x 39.2 mm

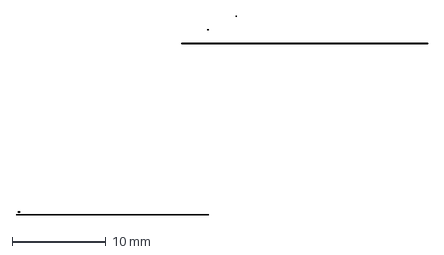
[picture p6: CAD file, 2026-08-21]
output/DXFs/081126_4Ford1MetaP100/P3/Horizontal.dxf
43.8 x 21.2 mm

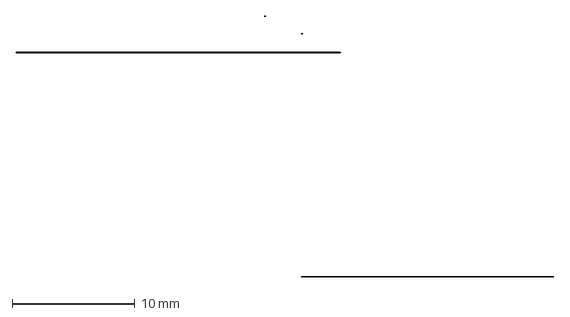
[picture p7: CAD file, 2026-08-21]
output/DXFs/081126_4Ford1MetaP100/P4/Horizontal.dxf
43.8 x 21.2 mm

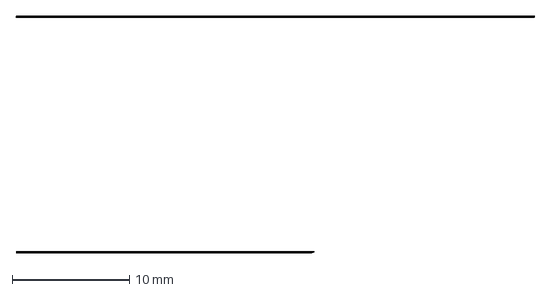
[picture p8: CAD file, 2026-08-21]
output/DXFs/081426_2Ford2Meta_P100/P1/Horizontal.dxf
44.3 x 20.2 mm

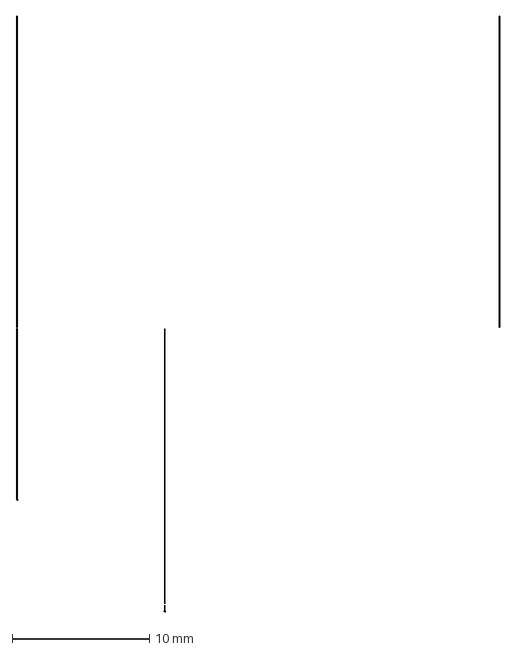
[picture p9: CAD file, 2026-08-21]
output/DXFs/081426_2Ford2Meta_P100/P2/Vertical.dxf
35.2 x 43.4 mm

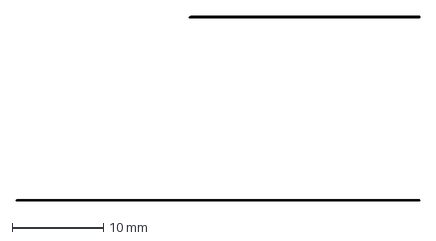
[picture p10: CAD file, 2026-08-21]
output/DXFs/081426_2Ford2Meta_P100/P3/Horizontal.dxf
44.3 x 20.2 mm

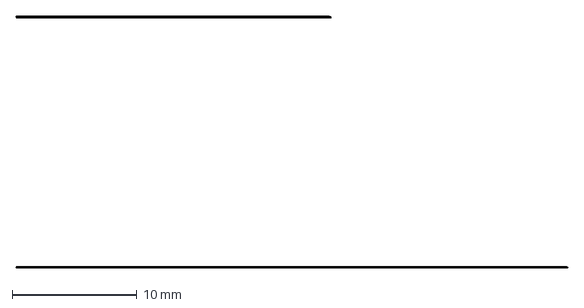
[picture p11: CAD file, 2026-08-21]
output/DXFs/081426_2Ford2Meta_P100/P4/Horizontal.dxf
44.3 x 20.2 mm

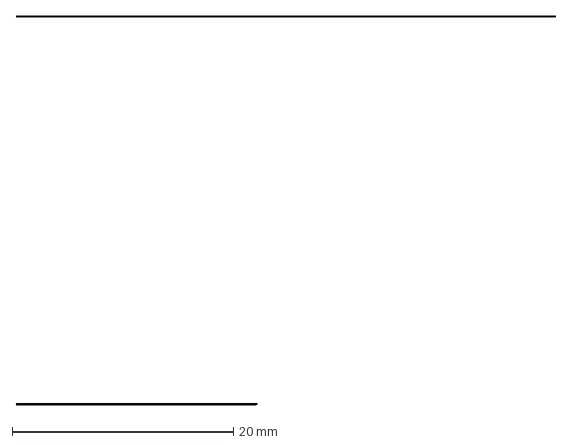
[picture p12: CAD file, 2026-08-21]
output/DXFs/081426_2MetaP150_1MetaP100/P1/Horizontal.dxf
48.8 x 35.2 mm

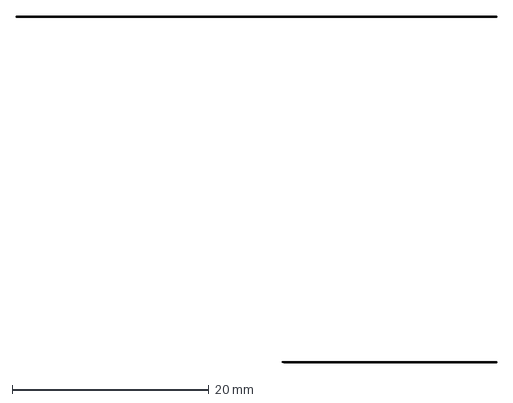
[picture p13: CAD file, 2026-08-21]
output/DXFs/081426_2MetaP150_1MetaP100/P2/Horizontal.dxf
48.8 x 35.2 mm

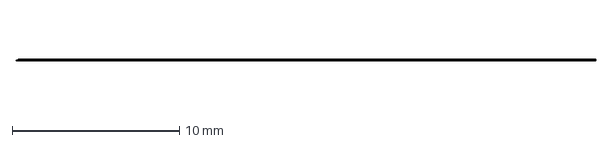
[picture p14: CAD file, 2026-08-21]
output/DXFs/081426_2MetaP150_1MetaP100/P3/Horizontal.dxf
34.6 x 0.07 mm

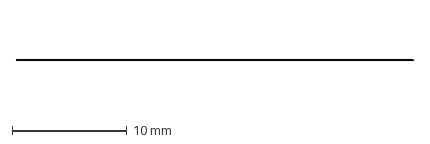
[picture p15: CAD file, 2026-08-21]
output/DXFs/081426_2MetaP150_1MetaP100/P4/Horizontal.dxf
34.6 x 0.07 mm

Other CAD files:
dxf/081326_AlignmentTest_v3_Marks/100mm_wafer_10x30mm_Horizontal_master.dxf
fusion/print-files/edge_datum_wafer_jig_al.stl
output/DXFs/081426_4Ford1MetaP100/P1/Vertical.dxf
output/DXFs/081426_4Ford1MetaP100/P2/Horizontal.dxf
dxf/080526_HorizDicev2.dxf
dxf/080526_VertDicev2.dxf
dxf/081326_AlignmentTest_v1_Marks/100mm_wafer_10x30mm_Horizontal_master.dxf
dxf/081326_AlignmentTest_v1_Marks/100mm_wafer_10x30mm_Vertical_master.dxf
dxf/081326_AlignmentTest_v2_Marks/100mm_wafer_10x30mm_Horizontal_master.dxf
dxf/081326_AlignmentTest_v2_Marks/100mm_wafer_10x30mm_Vertical_master.dxf
dxf/081326_AlignmentTest_v3_Marks/100mm_wafer_10x30mm_Vertical_master.dxf
dxf/100mm_10x30mm_Masters_NoMarker/100mm_wafer_10x30mm_Horizontal_master.dxf
dxf/100mm_10x30mm_Masters_NoMarker/100mm_wafer_10x30mm_Vertical_master.dxf
dxf/AlignmentTest_v2_Marks/100mm_wafer_10x30mm_Horizontal_master.dxf
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

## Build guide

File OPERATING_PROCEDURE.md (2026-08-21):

# Operating procedure — 100 mm wafer four-pass dicing

Slice the wafer GDS into four laser jobs, seat the wafer, and scribe each quadrant
on the UV galvo. The jig indexes on the table's 1 inch hole grid; the laser stays
fixed and field-centered, so indexing the jig moves the wafer under the beam.

## 1. Slice the GDS (slicer UI)

1. Launch the UI: `python slicing/slicer_app.py`.
2. **Source:** pick the wafer GDS. All cutlines are assumed on one layer — select
   that layer from the list.
3. **Output:** type a folder name; it lands under `output/<name>`.
4. **Mode:** Four windows. **Cut width:** 50 µm. Set a **wafer edge bead** (mm)
   only if the GDS runs cuts to the wafer edge (the standard masters already inset
   2 mm).
5. **Run.** The UI writes four field-centered jobs:
   `P1_jig_top_left.dxf`, `P2_jig_top_right.dxf`, `P3_jig_bottom_right.dxf`,
   `P4_jig_bottom_left.dxf`, plus a manifest and log. The slicer applies no
   calibration offset (`GLOBAL_*_OFFSET_UM = 0`); calibration lives in the taught
   stage stations — see `CALIBRATION_AND_SLIDING_NEST_NOTES.md`.

Each station DXF holds both horizontal and vertical cuts. To get them as
ready-split files, use `python slicing/build_pin_grid_set.py --combined <gds>
--cut-layer <layer>` instead of the UI.

## 2. Seat and tape the wafer

1. Set the jig on the table with all four dowels in the grid holes for the first
   position (P1 — see the table below).
2. Drop the wafer in and push it **forward against the primary flat** (front datum,
   sets Y + rotation) and **left against the X-datum pin** at the upper-left of the
   nest (sets X). The primary flat plus the pin fully locate it; the secondary flat
   is not used, so any wafer flat type seats the same way.
3. **Kapton-tape the wafer down** at the perimeter through the two tape gaps
   (180° apart). Tape **on top only, never underneath** — tape under the wafer
   rocks it and shifts focus. Keep tape clear of the scanned area (polyimide
   absorbs UV).

## 3. Scribe each quadrant (WinLase)

For each station, import its DXF and set:

- **Fill:** parallel (hatch), **0.01 mm** spacing — set the fill angle to the pass
  angle named by the DXF filename (e.g. `+45.0.dxf` → 45°; legacy H/V → 0° / 90°).
- **Mark speed:** 400 mm/s. **Passes:** 1 (mark once). **Loop the job 175×.**
- **Z / table height:** **0.463 in + jig base thickness (12.500 mm)** ≈ 24.26 mm.
- **Auto-centering OFF** — the DXF origin is the field center.

Run **P1 → P2 → P3 → P4 in order.** Do every pass-angle fill at each station before
moving. The current flow is stage-indexed: the jig stays pinned in place and
`dice_wafer.py` steps the OptiScan stage P1 → P4 in one armed run, moving the wafer
under the fixed field — do not lift or re-seat the jig between stations, and do not
disturb the tape.

| Pass | Front-left (alignment) pin hole | Table position (from left, front) | Exposes |
| --- | --- | --- | --- |
| P1 (top-left) | C1 R4 | (12.7, 88.9) mm | wafer bottom-right |
| P2 (top-right) | C3 R4 | (63.5, 88.9) mm | wafer bottom-left |
| P3 (bottom-right) | C3 R2 | (63.5, 38.1) mm | wafer top-left |
| P4 (bottom-left)  | C1 R2 | (12.7, 38.1) mm | wafer top-right |

Columns count from the table left, rows from the front; hole 1 is 12.7 mm in, then
25.4 mm pitch. The front-left pin is the reference — seating it puts the other three
dowels in their matching holes of the 4-space square. Adjacent stations are 2 grid
spaces (50.8 mm) apart. (P0 = C2 R3 centers the whole wafer in one field.)

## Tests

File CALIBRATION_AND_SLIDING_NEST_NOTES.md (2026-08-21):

# UV Laser Singulation calibration and sliding-nest notes

Last updated: 2026-08-21

Calibration is now DEFINITIVE and lives in the taught stage reference
`(84355, -19056)` in `laser-pc/optiscan_positions.json` (with the exposure copy in
`laser_pc/exposure_calibration.json`); the slicer/DXF `GLOBAL_*_OFFSET_UM` and the
per-station `WINDOW_OFFSETS_UM` are all `0`. Everything below is kept as the
measurement history that led there.

The `fusion/FusionPinGridJig*` and single-jig scripts referenced in the history below were
removed 2026-08-21; the current jig is the edge-datum `fusion/AlignerEdgePLA` /
`fusion/AlignerEdgeAL`. Old paths are left in the narrative as historical references (see git
history to recover the scripts).

## Coordinate convention

P1-P4 name the jig station, numbered clockwise from the table's top-left (P1
top-left, P2 top-right, P3 bottom-right, P4 bottom-left).

Indexing the jig moves the wafer, not the laser, so both axes invert and each
station exposes the diagonally opposite wafer quadrant.

| Label | Jig station | Exposed wafer area |
| --- | --- | --- |
| `P1` | top-left | bottom-right |
| `P2` | top-right | bottom-left |
| `P3` | bottom-right | top-left |
| `P4` | bottom-left | top-right |

Adopted 2026-08-08. The previous scheme labeled by exposed wafer quadrant
(`DXF11` = wafer top-left). Converting between them swaps `11` and `22` and
leaves `12` and `21` unchanged, which makes a mislabeled file easy to miss:
always confirm against the jig station, not the digits alone. Measurements
recorded below under the earlier heading dates use the old scheme where noted.

## Preliminary four-position seam measurements

Labels in this section and the next use the **superseded wafer-quadrant scheme**,
matching the archived old-jig output folders they describe. They are left as
recorded; do not renumber them.

These observations came from the first partial test image and must be checked
again after the full sample is run. No software correction has been applied yet.

- Approximate cut width used as the visual scale: `50 um`.
- Top-right (`DXF21`) appears approximately `10-20 um` higher than top-left
  (`DXF11`). Candidate correction: move `DXF21` down by the measured amount,
  after confirming the image and machine Y directions.
- The lines appear not to meet at the middle seam by approximately `75-100 um`.
- Candidate gap treatment after full-sample measurements: add approximately
  `75-100 um` total stitch overlap, or distribute approximately `37.5-50 um`
  extension to each neighboring exposure.
- Measure several locations along every seam before correcting. A constant
  error indicates translation; a changing error along a seam indicates rotation
  or skew and should not be treated as translation alone.

## Full-wafer bottom-right failure (2026-08-07)

- The full-wafer photograph shows the bottom-right horizontal pass (`DXF22`)
  displaced downward by approximately `8 mm` relative to the bottom-left pass
  (`DXF12`). This is roughly `160` nominal 50 um cut widths. Allow about
  `+/-1 mm` uncertainty from perspective, glare, and the photographed line bloom.
- Do **not** treat this as an 8 mm jig correction. The generated bottom-row
  horizontal cut occupies exactly the same local Y range in both files:
  `8.297 to 8.347 mm`.
- The likely cause is per-file automatic centering during import. The
  `DXF12/Horizontal.dxf` bounding-box center is `Y=-6.678 mm`; the centered
  alignment marker expands `DXF22/Horizontal.dxf` so its bounding-box center is
  `Y=+1.4345 mm`. Centering each file independently therefore produces an
  `8.1125 mm` relative Y error, matching the photographed bottom-right step in
  both magnitude and direction.
- The splitter emits only clipped geometry, so every DXF/GDS job has a
  different content bounding box. Any laser import option that centers or fits
  each drawing/cell independently destroys the intended `(0,0)` registration.
- The splitter coordinate math passed reconstruction validation: the four
  current files reproduce each master with zero XOR area, and the saved project
  files match the validated build byte-for-byte. The failure is therefore most
  consistent with import placement/centering, not the clipping or translation
  calculation.
- Before applying the earlier 10-20 um / 75-100 um fine corrections, run the
  laser (WinLase Pro) with auto-centering off so each job is placed at its true
  coordinates and the DXF origin lands on the field center. The splitter already
  writes every tile with its field center at the origin, so this reproduces the
  wafer exactly.

### Software resolution

- The fix is true-coordinate placement. The four-window splitter writes every
  tile with its field center at the DXF origin, and the laser (WinLase Pro) is
  run with auto-centering off so it places each job at its true coordinates and
  the DXF origin lands on the field center. This reproduces the wafer exactly and
  was confirmed on the machine with a placement probe.
- When this was written there were two splitters, the legacy old-jig profile for
  its 60 mm field and the pin-grid profile for 52 mm. The old-jig profile has
  since been removed and the field widened, so the one remaining splitter targets
  a 54 mm field.
- Cutting geometry remains exclusively on layer `0`.
- The corrected old-jig production set is stored separately as
  `output/DXFs/080726_FourPosDicer_OriginLocked`; the failed-run files were left
  unchanged for traceability.
- KLayout reopened all eight corrected files. Layer-0 horizontal and vertical
  reconstructions each had zero XOR area.

## Single sliding nest concept

Goal: move the seated wafer between the two Y positions without lifting or
prying it out of the nest.

- Replace the two fixed, overlapping wafer nests with one nest on a Y carriage.
- Carriage travel: exactly `50.000 mm` between front and rear indexed positions.
- Retain the existing outer-frame X indexing: the full jig still shifts `50 mm`
  left/right against the table side stops.
- Use two parallel Y guides so the carriage cannot rotate.
- Define both Y positions with hard stops or dowel-pin index holes rather than
  relying on printed friction alone.
- Preload the carriage against one guide and against the selected hard stop so
  every position approaches the same datums.
- Lock the carriage downward at each position to preserve wafer focus and
  prevent rocking. A spring plunger, removable index pin, or small toggle clamp
  is preferable to a loose printed detent.
- Add an accessible handle outside the laser field so the wafer can be shifted
  while remaining fully seated against its primary- and secondary-flat datums.
- Keep the track below the wafer support plane and keep rails/hardware outside
  the exposed wafer area where practical.

For a PLA prototype, a broad keyed slide can demonstrate the motion, but the
final repeatable version should use hard mechanical datums (for example dowel
pins or shoulder bolts) because sliding PLA clearance and wear are unlikely to
hold tens-of-microns repeatability by themselves.

## Four-pin grid-indexed nest

The sliding concept was superseded by a lift-and-index fixture using the table's
1 inch (`25.400 mm`) threaded-hole grid.

### Table and coordinate dimensions

- Grid pitch: `25.400 mm` (`1.000 inch`) center to center.
- First hole-center inset from the front and side edges: `12.700 mm`
  (`0.500 inch`). Table width is not used as a fixture datum.
- Measured hole/thread major opening: `6.000 mm`.
- Measured threaded minor diameter: `4.870 mm`.
- Directly measured laser-zero center from table left/front:
  `X=96.190 mm`, `Y=109.350 mm`.
- Two-grid-space indexing move in either axis: `50.800 mm`.
- Four-pass exposure centers on the wafer: `X,Y=+/-25.400 mm`.
- Nest center relative to the shared pin-pattern center:
  `X=+7.290 mm`, `Y=-4.950 mm`.

### Pin dimensions and tolerance

- Total pins: `4`, printed downward as an integral part of the platform. The
  inner 2 x 2 set was removed on 2026-08-08: the outer square alone fixes position
  and rotation, and four pins are far easier to line up when seating the plate.
- Nominal pin diameter: `4.650 mm` for all four pins, reduced from `4.700 mm`
  on 2026-08-08 after the tighter fit needed sanding to seat.
- Nominal diametral clearance against the measured 4.870 mm thread minor:
  `0.220 mm`; nominal radial clearance: `0.110 mm`.
- That clearance is spent against the `0.200 mm` stitch overlap. Plate shift is
  the radial clearance itself; plate rotation is that clearance over the
  `71.842 mm` pin-circle radius, which is `0.088 deg` and a further `0.041 mm`
  at the 27 mm field edge. Total `0.151 mm`, inside the overlap. A `4.600 mm`
  pin would reach `0.186 mm` and a `4.465 mm` pin `0.279 mm`, which exceeds it:
  do not open the pins further without widening the overlap to match.
- Total pin length below the platform: `5.000 mm`, of which the last
  `1.000 mm` is the entry taper, leaving `4.000 mm` straight.
- Entry taper height: `1.000 mm`, included in the 5.000 mm above.
- Tip diameter: `4.000 mm`, increasing to `4.650 mm` over the taper.
- The four pins are the corners of a `101.600 x 101.600 mm` square
  (`4 x 4` spaces), which gives the most rotational leverage available on the grid.
- PLA prototype dimensions are nominal. Verify a pin coupon before printing the
  full jig because extrusion width, shrinkage, and thread crests affect fit.

### Platform and nest dimensions

- Platform overall size: `128.000 x 128.000 mm`.
- Platform/wafer-support base thickness: `2.000 mm`.
- Continuous outside reinforcement bar: `4.000 mm` wide x `4.000 mm` high
  above the platform; total platform-plus-bar height is `6.000 mm`.
- Wafer diameter: `100.000 mm`.
- Primary-flat nominal length: `32.500 mm`; faces front (`-Y`).
- Secondary-flat nominal length: `18.000 mm`; faces left (`-X`) and sets
  rotation.
- Raised sidewall height above the 2 mm platform: `1.500 mm`.
- Sidewall thickness: `3.000 mm`.
- Radial wafer-pocket clearance: `0.500 mm` per side (`1.000 mm` diametral).
- Primary-flat clearance: `0.500 mm`.
- Secondary-flat rotational-datum clearance: `0.300 mm`, opened from `0.100 mm`
  on 2026-08-08. A standard secondary flat is `18.000 +/- 2.000 mm`, and a
  *short* flat cuts a shallower chord, so it sits further out: at `16.000 mm`
  the flat is `0.173 mm` proud of nominal. The old `0.100 mm` therefore
  interfered by `0.073 mm` on a spec-compliant wafer before any print error,
  which is what forced the sanding. `0.300 mm` clears the whole band.
- Primary-flat pickup opening: `15.000 mm` wide with a 45 degree bevel.
- Rear tape gap: `15.000 mm` wide with the same 45 degree bevel, on the plain
  arc directly opposite the primary flat. The pair gives a Kapton tab a run
  from platform to wafer at both ends without bridging the 1.5 mm lip. Like
  the pickup opening it cuts the raised wall only; the 2 mm platform stays
  continuous beneath the wafer.
- Side pickup tabs: one centered on the left and right edges,
  `10.000 mm` out by `24.000 mm` long, spanning z `2.000` to `6.000 mm`. Starting
  them at the top of the 2 mm platform leaves a `2.000 mm` undercut to hook a
  fingernail or tweezer tip under, so the plate lifts straight off its pins
  instead of being pried against the wafer or the nest wall. Overall plate width
  including both tabs is `148.000 mm`.
- The outside reinforcement bar has two centered notches, one aligned to the
  primary-flat opening and one to the rear tape gap, so a finger or tab can
  reach the wafer edge from outside the plate at either end. Each is
  `15.000 mm` wide at platform level and `23.400 mm` at
  the top, producing 45 degree side slopes through the 4 mm bar height.
- Pickup opening removes only the raised wall; the 3 mm support platform remains
  continuous and uncut.
- The aligner plate carries four engravings raised `0.500 mm` above the platform
  floor (additive prints cleaner than cutting them in).
- Top-left, left-aligned to the outer wall, is the title and centering position:
  `ALIGNER` then `P0 C2 R3` (seat the wafer here and the alignment pin lands in the
  field center, so the whole wafer is addressable in one shot).
- Top-right, right-aligned to the outer wall, is the station map, one hole per
  position: `P1 C1 R4`, `P2 C3 R4`, `P3 C3 R2`, `P4 C1 R2`.
- Bottom-left reads `ALIGNMENT PIN`, naming the outer pin nearest that corner. That
  pin is the one every engraved coordinate refers to. The four-pin pattern is rigid,
  so seating it fixes the other three; it always sits two grid spaces left of and
  two forward of the pin-pattern center.
- Bottom-right is the origin key: two stacked rows `C1=LEFT` / `R1=FRONT`,
  right-aligned to the outer wall.

### Wafer retention

The pocket locates the wafer; it does not hold it. Clearance cannot do both jobs
at once, and trying to make it do both is what produced the sanding:

- Tight enough to control rotation means tight enough to interfere with a
  spec-compliant wafer. Even the old `0.100 mm` secondary datum only limited
  rotation to `+/-0.637 deg`, which is `0.300 mm` at the 27 mm field edge, still
  larger than the `0.200 mm` stitch overlap. It was too tight to seat and too
  loose to locate.
- The `0.500 mm` radial clearance is a free-play envelope `2.5x` the stitch
  overlap. It only matters if the wafer moves relative to the nest, but nothing
  in the plate prevents that across the four re-seatings.

**Decision (2026-08-08): tape the wafer, do not print a spring.** Printed
cantilever preload fingers were considered and rejected. The nest wall is only
`1.500 mm` tall and `3.000 mm` thick, so a finger extruded from the platform is
fused to the floor along its length and behaves as a rib, not a beam; freeing it
would mean cutting a relief slot down through the 2 mm platform. Useful spring
force needs roughly a `1.400 mm` beam behind a `0.700 mm` slot, and that slot is
under two extrusion widths on a 0.4 mm nozzle, so it tends to fuse closed or
print ragged. PLA also creeps under sustained deflection, so the printed preload
decays.

Kapton tabs over the top, bridging nest wall to wafer at the extreme perimeter,
remove the movement entirely rather than reducing it, and cost nothing to undo.
Tape on top, never underneath: `0.060` to `0.090 mm` of tape below a `0.525 mm`
wafer rocks it and moves focus. Polyimide absorbs UV strongly, so keep the tabs
clear of the scanned area.

### Four-position pin map

Grid columns are numbered from the left and rows from the front, starting at
one. Labels are jig stations per the coordinate convention above.

| Folder | Jig station | Pin columns/rows | Engraved hole | Exposed area |
| --- | --- | --- | --- | --- |
| `P1` | top-left | columns `1,5`; rows `4,8` | `C1 R4` | bottom-right |
| `P2` | top-right | columns `3,7`; rows `4,8` | `C3 R4` | bottom-left |
| `P3` | bottom-right | columns `3,7`; rows `2,6` | `C3 R2` | top-left |
| `P4` | bottom-left | columns `1,5`; rows `2,6` | `C1 R2` | top-right |

### Center (P0) pin map

The same four-position plate centers the wafer at laser zero when its four pins are
seated at the center holes (position `P0`), whose pattern center is grid column `4`,
row `5`:

- Pins: columns `2,6`; rows `3,7`. Engraved front-left pin: `C2 R3`, at
  `(38.100,63.500) mm` from the table left/front.
- Pin-pattern center: `(88.900,114.300) mm` from the table left/front.
- Wafer center after the `(+7.290,-4.950) mm` nest offset:
  `(96.190,109.350) mm`, exactly the directly measured laser-zero center.

### Fusion packages

- Four-position workflow (also centers via P0): `fusion/FusionPinGridJig`. The
  separate `FusionPinGridCenterJig` was retired 2026-08-11 once P0 covered centering.

## Pin-grid DXF/GDS production profile

Revised 2026-08-08. The window a job occupies is now derived from the pitch and the
stitch alone, so the declared field is free to be larger than the window.

- Declared exposure/file bounds: `54.000 x 54.000 mm`.
- Window occupied per job: `51.000 mm`, its own half of the `50.800 mm` pitch plus
  the stitch, centred in the 54 mm field with `1.500 mm` clear on every side.
- Four field centers on the wafer: `X,Y=+/-25.400 mm`.
- Neighboring-center spacing: `50.800 mm`, matching the two-hole grid move.
- Total stitch overlap: `0.200 mm`; each job extends `0.100 mm` across the nominal
  X=0 and Y=0 seam, which covers the 75-100 um mismatch measured above. Raising it
  past `3.200 mm` would push a window outside the declared field, and the splitter
  refuses that.
- Margin from the declared 54 mm window to each edge of the `60 mm` usable field:
  `3 mm`.
- Placement is by true coordinates: each tile is written with its field center
  at the DXF origin, so the laser (WinLase Pro) run with auto-centering off
  places every job at its true coordinates with the origin on the field center.
- Double-exposed area per wafer: `0.4925 mm2` of `49.1333 mm2`, about `1.00%`. Of
  that, `0.0700 mm2` is the 28 grid crossings where the horizontal and vertical
  files meet and `0.4225 mm2` is the deliberate seam stitch. Acceptable because the
  wafer is scored partway through rather than cut.
- `CLIP_MODE` now matters: at the old 52 mm field `partition` and `full_window`
  produced identical boxes, but with a 54 mm field `full_window` overlaps
  neighbours by `3.200 mm` and exposes that whole band twice.
- Cutting geometry remains on layer `0`, with a maximum width of `50 um`.
- Master-generator edge bead is controlled by the single top-level
  `EDGE_BEAD_MM` variable in `generate_100mm_10x30mm_masters.py`; units are
  millimeters. Current production value: `2.000 mm`.
- Validated production output:
  `output/DXFs/080826_FourPosDicer_PinGrid54mm`. The 52 mm set
  `080726_FourPosDicer_PinGrid52mm` is superseded and kept only for traceability. Relabeled to jig-station names
  on 2026-08-08 and revalidated: layer-0 reconstruction XOR area is zero against
  both masters, the field-placement self-test confirms every tile's layer-0
  geometry fits within `+/-30 mm` (the usable field) of the origin with the origin
  at the field center, and all eight DXFs are byte-identical to the files they replaced.
- One production splitter only: `slicing/split_klayout.py`. The
  byte-identical `split_klayout_four_windows_pin_grid.py` duplicate was removed
  on 2026-08-08.

## Print v2 and global-offset calibration (2026-08-11)

Measured on the 081126 alignment test (stations P1-P4, front pins seated in the
4th row of holes, laser auto-centering off): the exposure landed **+3.017 mm in X
and -1.286 mm in Y** off the wafer flats. The left seam line read `12.20 mm` from
the minor (secondary, -X) flat against `9.183 mm` expected; the bottom seam line
read `16.00 mm` from the major (primary, -Y) flat against `17.286 mm` expected.
The usable optical field is a `60 x 60 mm` square -- the galvo's full field is
about `78.485 mm`, but it weakens toward the edges, so only the central 60 mm is
used -- so the corrected geometry (widest marks at `+/-28.5 mm`) stays well inside it.

Re-measured after applying that correction: the left line read `9.35 mm` from the
minor flat (`9.183 mm` expected, `+0.17 mm` residual) and the bottom line
`17.23 mm` from the major flat (`17.286 mm` expected, `-0.06 mm` residual) -- both
below the `0.200 mm` stitch overlap. Both residuals kept the sign of the original
error (an under-correction). Correcting the full residual (`-3186.7 / +1345.7`)
overtuned given the noise, so the difference was split with the first correction and
half applied: X by `85 um` (`-3016.7 -> -3101.7`) and Y by `30 um`
(`+1285.7 -> +1315.7`).

The same offset is corrected two ways, and only ONE may be active at a time:

- **Software (current jig):** `GLOBAL_X_OFFSET_UM = -3101.7`,
  `GLOBAL_Y_OFFSET_UM = +1315.7` in `slicing/split_klayout.py`, applied
  to every job after it is centered on its field. The `081126_FullDice_v3` set is
  built with these split-difference values; the earlier `081126` and
  `081126_AlignmentTest_v2` sets carry the original `-3016.7 / +1285.7` they were
  measured against.
- **Jig (print v2):** `NEST_CALIBRATION_X/Y = +3.187 / -1.346` in
  `fusion/FusionPinGridJig/FusionPinGridJig.py` shifts the nest relative to the pins
  so a field-centered exposure lands correctly. This is the full best-known offset
  (the software split-difference under-corrects by design), so the jig should need
  only a small re-trim after printing. **Reset the software `GLOBAL_*_OFFSET_UM` to
  0 once a print-v2 jig is in use**, or the DXF and the jig double-correct by ~3 mm.

Print-v2 jig changes to `FusionPinGridJig` (the redundant `FusionPinGridCenterJig`
was retired 2026-08-11; P0 centers the wafer on the four-position plate):

- Pin diameter `4.650 -> 4.700 mm` (tip `4.000 -> 4.050`); fit vs the `4.870 mm`
  hole minor tightens from `0.220` to `0.170 mm` diametral clearance.
- Nest clearances reduced 35%: radial and primary-flat `0.500 -> 0.325 mm`,
  secondary datum `0.300 -> 0.195 mm`.
- Base thickness `2.000 -> 3.000 mm` (pin length and platform follow `BASE_THICKNESS`).
- Engraving text `3.0 -> 3.5 mm` and **additive (raised)** rather than cut.
- Engraving relayout: the title `ALIGNER` and centering line `P0 C2 R3` moved to the
  **top-left** (left-aligned); the `P1-P4` station map stays **top-right**
  (right-aligned). Previously both shared one top-right block. Verify both fit in
  Fusion.

Other 2026-08-11 changes:

- Quadrant outputs renamed `DXF11/12/21/22 -> P1/P2/P3/P4`, clockwise from the
  table top-left (P1 top-left ... P4 bottom-left), and grid labels are now
  **1-indexed** (`C1`/`R1` = first hole). The engraved reference pin moved to the
  front-left of each station.
- Combining orientations into one `Combined.dxf` per station was tried and
  **removed** (it did not expose well); sets are separate `Horizontal.dxf` /
  `Vertical.dxf` per station again.
- Marker-free full dice: `slicing/generate_100mm_10x30mm_masters_nomarker.py` reuses
  the base 10x30 generator's geometry but omits the centered plus marker, writing
  masters to `dxf/100mm_10x30mm_Masters_NoMarker`. Full-dice test set
  `output/DXFs/081126_FullDice_v3` (10x30 mm production dice, no alignment marker)
  builds and validates clean, carrying the software offset for the current jig.
- The field-placement self-test checks the `60 mm` usable field (`+/-30 mm`), not
  the `54 mm` qualified field.

## Nest tightened to flat-only datuming (2026-08-12)

The printed jig moved to pressed steel dowels in bosses and a tight bounding-box
plate (`123.53 x 116.63 mm`; see `fusion/FusionPinGridJig`), and the wafer nest was
retuned to locate the wafer **purely on its two flats** for maximum repeatability.
The calibrated print in hand was very roomy even in PLA, so the flats were pulled
in hard while the arc was left loose enough never to touch first.

Clearances now, in `FusionPinGridJig.py` (these supersede the v2 values in the
"Platform and nest dimensions" section above):

- Primary flat (front datum) and secondary flat (left datum): **0.175 mm each**
  (the calibrated print's nest was `0.500` primary / `0.300` secondary).
- Radial arc: **0.500 mm**. With both flats home the wafer center sits
  `sqrt(0.175^2 + 0.175^2) = 0.248 mm` off nest center, so the arc must exceed that
  or the front-left arc jams before the flats seat. `0.500` leaves `~0.25 mm` arc
  clearance, sized so every wafer -- including undersize, which seats deeper into
  the corner -- clears the arc and datums on its flats.

**Dowel length:** the bore runs through the `12.5 mm` base (thickened to `12.5 mm`
for warp resistance; the raised boss was dropped, so the bore goes through the
solid slab), so cut each 3/16 in steel dowel to about **`13 mm`** (~8 mm engaged +
5 mm protruding) to match the v2 printed pins.
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

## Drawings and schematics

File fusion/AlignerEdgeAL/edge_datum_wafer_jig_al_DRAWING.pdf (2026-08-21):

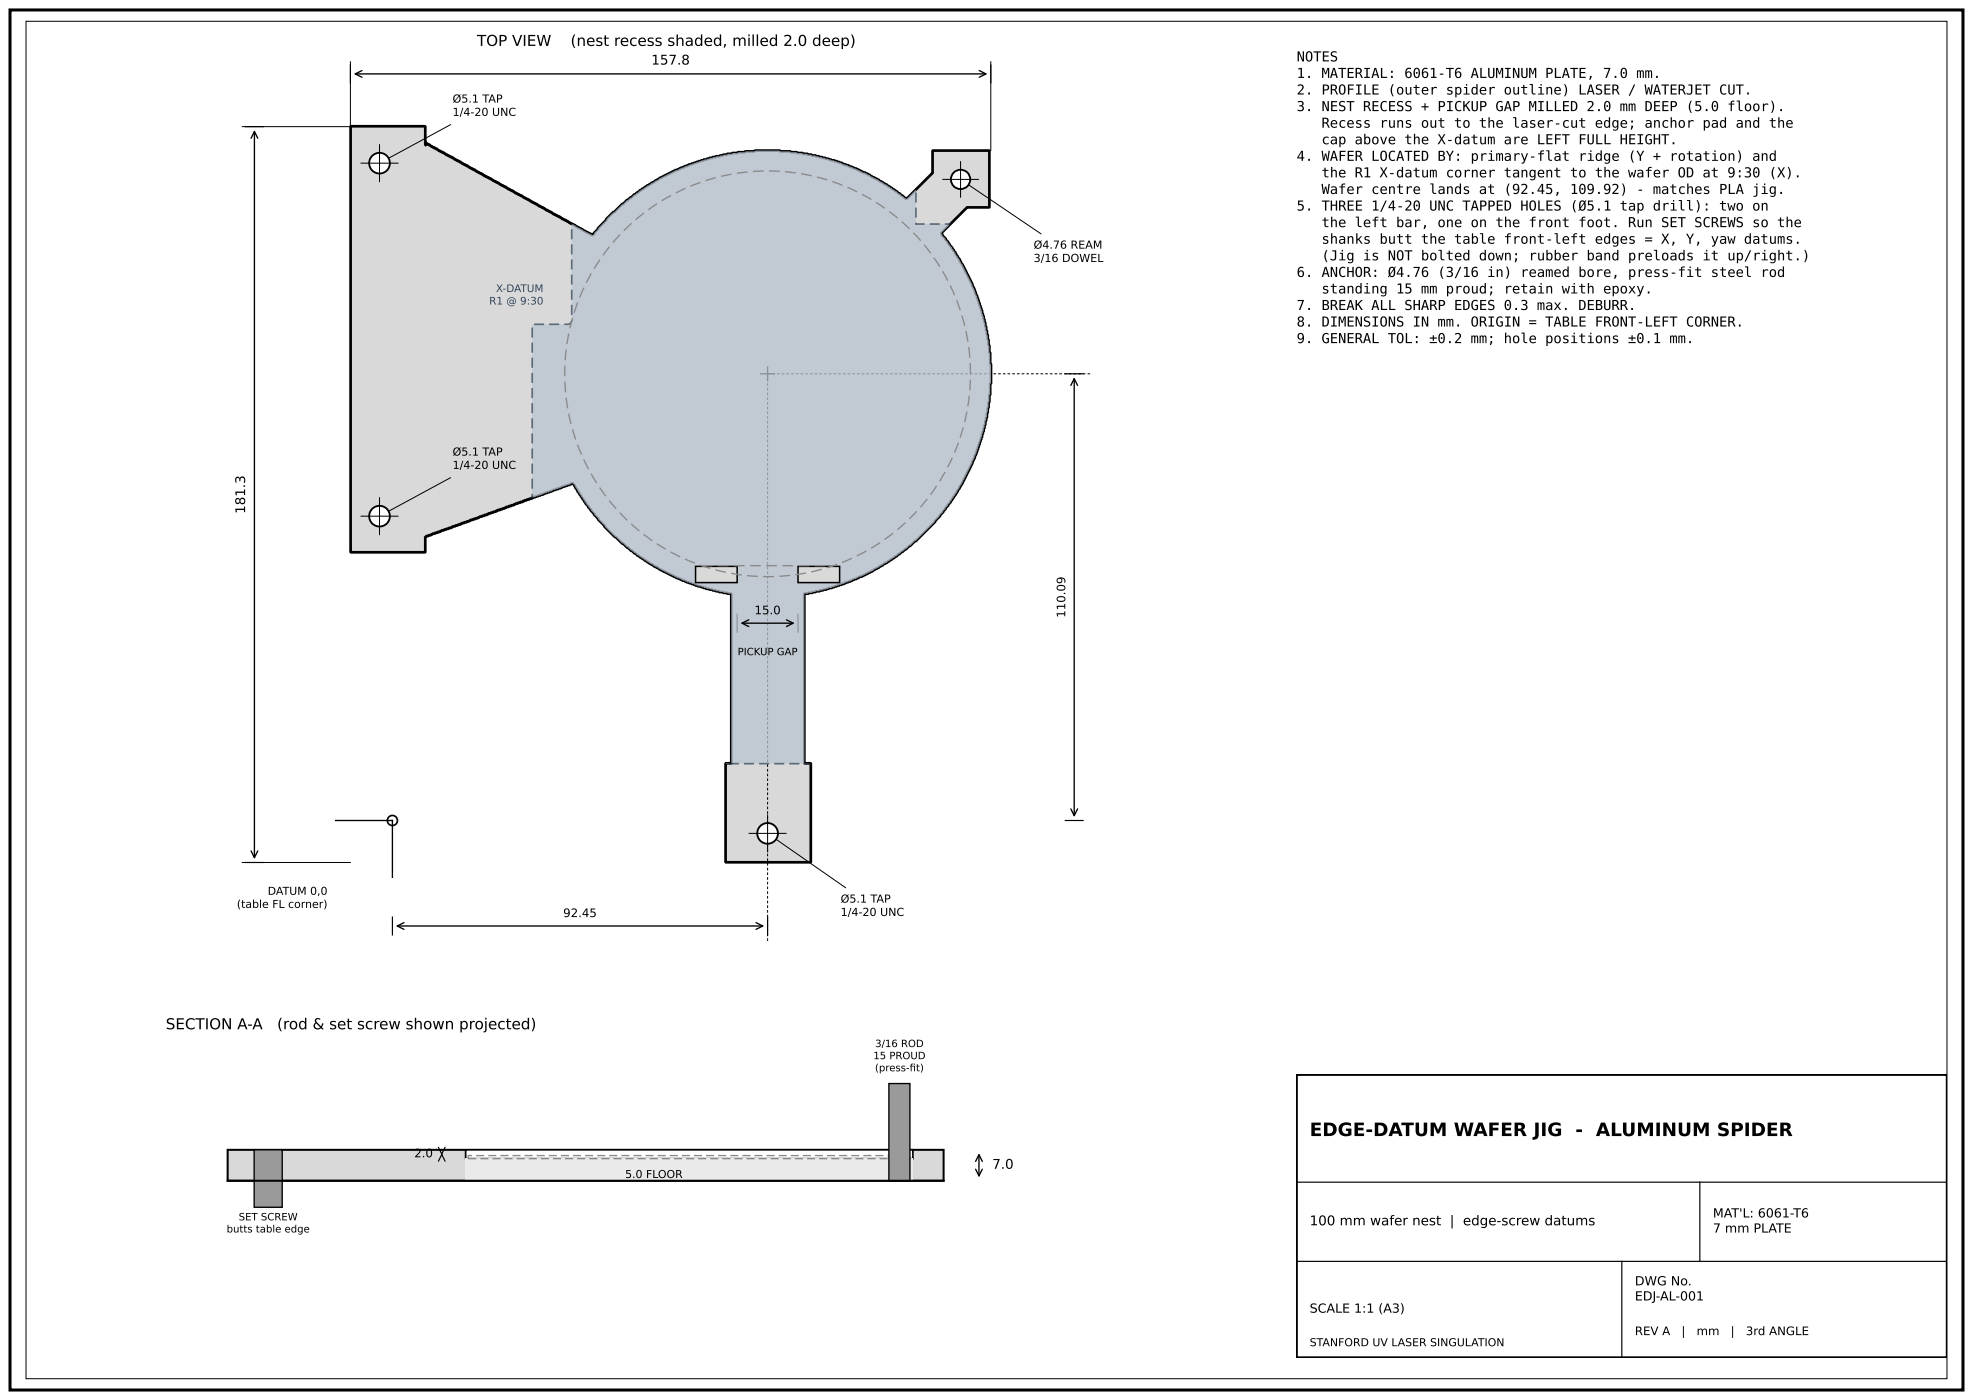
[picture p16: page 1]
DATUM 0,0; Ø5.1 TAP 1/4-20 UNC; Ø4.76 REAM 3/16 DOWEL; PICKUP GAP; X-DATUM R1 @ 9:30; TOP VIEW; (nest recess shaded, milled 2.0 deep); 3/16 ROD 15 PROUD (press-fit); 5.0 FLOOR; MAT'L: 6061-T6 7 mm PLATE; SCALE 1:1 (A3); DWG No. EDJ-AL-001

NOTES
1. MATERIAL: 6061-T6 ALUMINUM PLATE, 7.0 mm.
2. PROFILE (outer spider outline) LASER / WATERJET CUT.
3. NEST RECESS + PICKUP GAP MILLED 2.0 mm DEEP (5.0 floor).
Recess runs out to the laser-cut edge; anchor pad and the
cap above the X-datum are LEFT FULL HEIGHT.
4. WAFER LOCATED BY: primary-flat ridge (Y + rotation) and
the R1 X-datum corner tangent to the wafer OD at 9:30 (X).
Wafer centre lands at (92.45, 109.92) - matches PLA jig.
5. THREE 1/4-20 UNC TAPPED HOLES (Ø5.1 tap drill): two on
the left bar, one on the front foot. Run SET SCREWS so the
shanks butt the table front-left edges = X, Y, yaw datums.
(Jig is NOT bolted down; rubber band preloads it up/right.)
6. ANCHOR: Ø4.76 (3/16 in) reamed bore, press-fit steel rod
standing 15 mm proud; retain with epoxy.
7. BREAK ALL SHARP EDGES 0.3 max. DEBURR.
8. DIMENSIONS IN mm. ORIGIN = TABLE FRONT-LEFT CORNER.
9. GENERAL TOL: ±0.2 mm; hole positions ±0.1 mm.

(table FL corner)

SECTION A-A (rod & set screw shown projected)

EDGE-DATUM WAFER JIG - ALUMINUM SPIDER

SET SCREW
butts table edge

100 mm wafer nest | edge-screw datums

REV A | mm | 3rd ANGLE

STANFORD UV LASER SINGULATION

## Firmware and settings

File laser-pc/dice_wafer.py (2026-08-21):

"""One-button wafer dicing: OptiScan III stage + WinLase Pro, fully sequenced.

For each station P1..P4 it moves the stage to the taught position, (optionally) sets
focus, then marks that station's pre-built WinLase job. The jig stays put; the stage
indexes the wafer under the fixed field, so stage position i lines up with job i.

Pipeline it ties together:
  1. laser-pc/winlase_build_jobs.py  -> builds <set>/WinLaseJobs/<set>_P1..P4.wlj
  2. laser-pc/optiscan.py jog        -> teaches laser-pc/optiscan_positions.json (P1..P4)
  3. THIS script                  -> move -> (focus) -> mark, P1->P2->P3->P4

SAFETY -- this can fire the laser, so it is gated:
  * Default is SIMULATE: real stage moves, but marking is faked (a short dwell).
    Run it this way first to prove the motion and sequencing with NO laser.
  * Pass --arm to actually load and mark jobs through WinLase.
  * LASER-PROFILE GATE: after arming, before ANY stage motion, every job is read back
    and its profile checked against the confirmed WinLase settings (power 100 %,
    frequency 30 kHz, mark speed 100 mm/s). Any mismatch aborts the run -- no motion,
    no firing. Each job is re-checked once more at mark time. This script never WRITES
    laser power or frequency; it only reads and verifies them.
  * A countdown precedes the run; pressing a key during the countdown, or between
    stations / between mark passes, aborts (stage controlled-stop `I` + WinLase
    TerminateMark). Mid-pass you cannot interrupt in software -- keep a hand on the
    hardware e-stop. This live-laser path could not be tested off the machine.
  * The built .wlj job files are KEPT after a run, so a set can be re-marked without
    rebuilding through WinLase; pass --delete-jobs to remove them after a clean armed run.

WinLase note: the WinLase GUI and the COM server can't both hold the marker library,
so CLOSE the WinLase GUI before an armed run. Python 3.8, no network; serial via
pyserial-or-pywin32 (see optiscan.py), WinLase via pywin32 (win32com).

    python laser-pc/dice_wafer.py output/DXFs/081326_AlignmentTest_v2                 # SIMULATE
    python laser-pc/dice_wafer.py output/DXFs/081326_AlignmentTest_v2 --list          # show plan only
    python laser-pc/dice_wafer.py output/DXFs/081326_AlignmentTest_v2 --arm           # LIVE laser
    python laser-pc/dice_wafer.py <set> --arm --home-after     # passes from dice_passes.csv (or --passes N)
"""

from __future__ import annotations

import argparse
import csv
import json
import sys
import time
from pathlib import Path

from optiscan import OptiScan  # same laser-pc/ dir

STATION_ORDER = ("P1", "P2", "P3", "P4")
DEFAULT_PASSES = 175
# Usable stage window (absolute um) after the 2026-08 re-datum; keep in sync with
# dice_ui.REACHABLE_UM and the exposure exposure_calibration.json reachable_um. Used to reject
# stale / out-of-datum taught stations BEFORE any motion (a stale old-datum P1 has negative X,
# unreachable on this datum -> the stage silently fails to move X).
# -Y floor is -38140 (NOT the -57210 hard stop): the stage hits a PIPE at the back past that,
# so clamping here protects the hardware and improves alignment. Keep in sync across repos + optiscan.
REACHABLE_UM = {"x_min": 16236, "x_max": 138529, "y_min": -38140, "y_max": 0}
DEFAULT_PASSES_FILE = Path(__file__).resolve().parent / "dice_passes.csv"
DEFAULT_COUNTDOWN_S = 10

# Required laser profile -- must match the WinLase "Vector Graphic -> Properties ->
# Profile" the operator confirmed: power 100 %, frequency 30 kHz, mark speed 100 mm/s.
# Before ANY stage motion or firing, every job is read back and checked against these;
# a mismatch aborts the whole run. GetObjProfile index map (same as winlase_build_jobs):
# [0] = mark speed (bits/mSec), [5] = laser power %, [9] = T1 frequency (kHz).
EXPECTED_LASER_POWER_PCT = 100.0
EXPECTED_FREQ_KHZ = 30.0
EXPECTED_MARK_SPEED_MM_S = 100.0
POWER_TOLERANCE_PCT = 0.5
FREQ_TOLERANCE_KHZ = 0.1
SPEED_TOLERANCE_MM_S = 10.0
PROFILE_SPEED_IDX, PROFILE_POWER_IDX, PROFILE_FREQ_IDX = 0, 5, 9

# WinLase marking is ASYNCHRONOUS: MarkAllObj starts a pass and returns; GetBusyStatus
# polls for completion. So we wait for idle before starting a job (drains any prior
# job's tail) and after every pass (so a job fully finishes before it is closed and the
# next one loads -- otherwise closing/loading mid-mark wedges WinLase "busy").
MARK_POLL_S = 0.02           # GetBusyStatus poll interval
MARK_SETTLE_S = 0.1          # let a just-issued mark register as busy before we poll for done
MARK_WAIT_TIMEOUT_S = 120.0  # max wait for one pass (or a job transition) to go idle

# Time-estimate (ETA): empirical, measured live. Emitted as "[eta] ..." lines that the
# launcher UI mirrors into its Est. time field. A small per-set cache warm-starts it so a
# repeat run shows a number from t=0. Cosmetic only -- never affects motion or firing.
ETA_LOG_INTERVAL_S = 15.0    # min seconds between [eta] progress lines
DEFAULT_MOVE_S = 8.0         # rough stage-move guess until a real move is timed
DEFAULT_ETA_CACHE = Path(__file__).resolve().parent / ".dice_eta.json"


def _aborted() -> bool:
    """True if a key was pressed (non-blocking), on Windows."""
    try:
        import msvcrt
    except ImportError:
        return False
    if msvcrt.kbhit():
        msvcrt.getch()
        return True
    return False


# ------------------------------------------------------------------- WinLase COM
class WinLaseMarker:
    """Loads and marks pre-built .wlj jobs through the WinLase automation server."""

    def __init__(self):
        try:
            from win32com.client import dynamic
        except ImportError as exc:
            raise SystemExit(
                "pywin32 is not installed in this venv, so WinLase COM is unavailable.\n"
                "Install it offline (wheels are in venv\\wheels), then re-run:\n"
                "    pip install --no-index --find-links venv\\wheels pywin32\n"
                "    python venv\\Scripts\\pywin32_postinstall.py -install"
            ) from exc
        # Late/dynamic binding on purpose -- see the note in winlase_build_jobs.py:
        # WinLase's non-retval [out] params break early binding; dynamic auto-returns them.
        self.m = dynamic.Dispatch("Winlase.Automate")
        self.m.AttachToMarker()
        if int(self.m.GetScanCardCount()) < 1:
            raise SystemExit("WinLase reports no scan card; can't mark. Run on the laser PC.")
        self.bits_per_mm = int(self.m.GetLensCalFactor(0, 0))
        if self.bits_per_mm <= 0:
            raise SystemExit("GetLensCalFactor returned <= 0; is a lens cal loaded?")

    def ready(self) -> bool:
        return int(self.m.GetBusyStatus(0)) == 0

    def _wait_not_busy(self, abort, timeout_s: float) -> bool:
        """Poll until WinLase is idle (two consecutive not-busy reads, so a transient 0
        can't be mistaken for done). Returns True when idle, False if aborted mid-wait.
        Raises TimeoutError (after TerminateMark) if it never goes idle in time."""
        t0 = time.time()
        idle_hits = 0
        while True:
            if abort():
                return False
            if self.ready():
                idle_hits += 1
                if idle_hits >= 2:
                    return True
            else:
                idle_hits = 0
            if time.time() - t0 > timeout_s:
                try:
                    self.m.TerminateMark()
                except Exception:
                    pass
                raise TimeoutError("WinLase stayed busy > %.0f s" % timeout_s)
            time.sleep(MARK_POLL_S)

    def _check_active_params(self, label: str):
        """Read every object's profile in the ACTIVE job and compare to the required
        laser settings. Returns a list of human-readable problem strings (empty = OK)."""
        problems = []
        count = int(self.m.GetObjCount())
        if count < 1:
            return ["%s: job holds no objects to verify" % label]
        for obj in range(count):
            prof = list(self.m.GetObjProfile(obj, 0))
            power = float(prof[PROFILE_POWER_IDX])
            freq = float(prof[PROFILE_FREQ_IDX])
            speed = float(prof[PROFILE_SPEED_IDX]) / self.bits_per_mm * 1000.0
            if abs(power - EXPECTED_LASER_POWER_PCT) > POWER_TOLERANCE_PCT:
                problems.append("%s obj %d: laser power %.3f %% (need %.0f %%)"
                                % (label, obj, power, EXPECTED_LASER_POWER_PCT))
            if abs(freq - EXPECTED_FREQ_KHZ) > FREQ_TOLERANCE_KHZ:
                problems.append("%s obj %d: frequency %.2f kHz (need %.2f kHz)"
                                % (label, obj, freq, EXPECTED_FREQ_KHZ))
            if abs(speed - EXPECTED_MARK_SPEED_MM_S) > SPEED_TOLERANCE_MM_S:
                problems.append("%s obj %d: mark speed %.0f mm/s (need %.0f mm/s)"
                                % (label, obj, speed, EXPECTED_MARK_SPEED_MM_S))
        return problems

    def verify_job_params(self, wlj: Path):
        """Load a job read-only, check its laser profile, close it. Returns problems."""
        idx = int(self.m.LoadJobFromFile(str(wlj.resolve())))
        try:
            self.m.SetActiveJob(idx)
            return self._check_active_params(wlj.name)
        finally:
            try:
                self.m.CloseJob(idx)
            except Exception:
                pass

    def mark_job(self, wlj: Path, loops: int, abort, on_pass=None) -> bool:
        """Load a job and mark it `loops` times. Returns False if aborted.

        `on_pass(i, dt)`, if given, is called after each pass with its index and measured
        wall-clock seconds (trigger -> idle), for the live time estimate. It is best-effort:
        an exception in it is swallowed so a cosmetic estimate can never abort a mark."""
        job_index = int(self.m.LoadJobFromFile(str(wlj.resolve())))
        self.m.SetActiveJob(job_index)
        # Last-instant re-check right before firing (defence in depth on top of the
        # pre-flight gate): never mark a job whose laser profile is not exactly right.
        problems = self._check_active_params(wlj.name)
        if problems:
            try:
                self.m.CloseJob(job_index)
            except Exception:
                pass
            raise RuntimeError("laser profile check failed at mark time:\n  "
                               + "\n  ".join(problems))
        try:
            # Make sure the marker is idle before we start -- this also drains the tail
            # of the previous station's job so loading/closing never collides with a mark.
            if not self._wait_not_busy(abort, MARK_WAIT_TIMEOUT_S):
                self.m.TerminateMark()
                return False
            for i in range(loops):
                if abort():
                    self.m.TerminateMark()
                    return False
                t_pass = time.time()
                self.m.MarkAllObj(0)          # async: starts this pass, returns immediately
                time.sleep(MARK_SETTLE_S)     # let the mark register as busy before polling
                if not self._wait_not_busy(abort, MARK_WAIT_TIMEOUT_S):  # wait for THIS pass to finish
                    self.m.TerminateMark()
                    return False
                if on_pass is not None:
                    try:
                        on_pass(i, time.time() - t_pass)
                    except Exception:
                        pass                  # ETA is cosmetic; never let it break a mark
        finally:
            try:
                self.m.CloseJob(job_index)    # safe now: the job has fully finished marking
            except Exception:
                pass
        return True

    def stop(self) -> None:
        try:
            self.m.TerminateMark()
        except Exception:
            pass

    def close(self) -> None:
        try:
            self.m.ReleaseMarker()
        except Exception:
            pass


# ------------------------------------------------------------------ time estimate
def _fmt_dur(seconds: float) -> str:
    seconds = int(round(max(0.0, seconds)))
    h, rem = divmod(seconds, 3600)
    m, s = divmod(rem, 60)
    return "%d:%02d:%02d" % (h, m, s) if h else "%d:%02d" % (m, s)


def load_eta_cache(path: Path, set_name: str) -> dict:
    """Warm-start per-pass/move seconds for a set from a prior armed run. Returns {} for
    a missing, unreadable, or malformed cache -- every shape is validated, so a bad or
    hand-edited .dice_eta.json can never raise into (and abort) a dicing run."""
    try:
        data = json.loads(path.read_text(encoding="utf-8"))
        if not isinstance(data, dict):
            return {}
        entry = data.get(set_name)
        if not isinstance(entry, dict):
            return {}
        warm = {}
        per_pass = entry.get("per_pass")
        if isinstance(per_pass, dict):
            for k, v in per_pass.items():
                if isinstance(v, (int, float)):
                    warm[str(k)] = float(v)
        if isinstance(entry.get("move"), (int, float)):
            warm["move"] = float(entry["move"])
        return warm
    except (OSError, ValueError, TypeError):
        return {}


def save_eta_cache(path: Path, set_name: str, per_pass: dict, move_s) -> None:
    """Persist this run's measured pace so the next run of the same set estimates from
    t=0. Best-effort: any failure is swallowed (an ETA cache is never worth an error)."""
    try:
        data = {}
        if path.is_file():
            try:
                data = json.loads(path.read_text(encoding="utf-8"))
            except ValueError:
                data = {}
        if not isinstance(data, dict):   # a valid-but-non-object file must not crash the write
            data = {}
        entry = {"per_pass": {k: round(v, 3) for k, v in per_pass.items() if v is not None}}
        if move_s is not None:
            entry["move"] = round(move_s, 3)
        entry["updated"] = time.strftime("%Y-%m-%dT%H:%M:%S")
        data[set_name] = entry
        path.write_text(json.dumps(data, indent=2), encoding="utf-8")
    except (OSError, ValueError, TypeError):
        pass


class EtaTracker:
    """Live, empirical time estimate for a dicing run.

    Every mark pass of a station reloads the same job, so its wall-clock time is
    near-constant; we measure it (and each stage move) and extrapolate over the
    remaining passes and stations. No geometry, no machine constants -- just measured
    pace, refined as the run proceeds, so the estimate captures galvo jumps, fill,
    settle and poll overhead that a computed model cannot reach. A per-set cache
    warm-starts it. Estimates are marked '~' and are best-effort.
    """

    def __init__(self, labels, passes, warm=None, final_move=False, emit=print):
        self.labels = list(labels)
        self.passes = int(passes)
        self.warm = dict(warm or {})
        self.final_move = bool(final_move)
        self.emit = emit
        self.per_pass = {label: [] for label in self.labels}
        self.moves = []
        self.run_t0 = None
        self.cur_idx = 0
        self.cur_pass = 0
        self._last_emit = 0.0

    # -- measurement --------------------------------------------------------
    def start(self):
        self.run_t0 = time.time()

    def record_move(self, seconds):
        self.moves.append(float(seconds))

    def on_station_start(self, idx, label):
        self.cur_idx = idx
        self.cur_pass = 0
        self._maybe_emit(force=True)

    def on_pass(self, idx, label, pass_i, dt):
        self.cur_idx = idx
        self.cur_pass = pass_i + 1
        self.per_pass[label].append(float(dt))
        # Refresh on the first real sample of a station (the estimate sharpens there).
        self._maybe_emit(force=(len(self.per_pass[label]) == 1))

    # -- estimation ---------------------------------------------------------
    def _move_est(self):
        if self.moves:
            return sum(self.moves) / len(self.moves)
        return self.warm.get("move", DEFAULT_MOVE_S)

    def _per_pass_est(self, label):
        vals = self.per_pass.get(label, [])
        if len(vals) >= 2:
            return sum(vals[1:]) / len(vals[1:])   # drop the cold-start first pass
        if len(vals) == 1:
            return vals[0]
        if label in self.warm:
            return self.warm[label]
        measured = [v for lst in self.per_pass.values() for v in lst]
        if measured:
            return sum(measured) / len(measured)
        warm_vals = [self.warm[l] for l in self.labels if l in self.warm]
        if warm_vals:
            return sum(warm_vals) / len(warm_vals)
        return None

    def _remaining(self):
        known = True
        total = 0.0
        cur = self._per_pass_est(self.labels[self.cur_idx])
        if cur is None:
            known, cur = False, 0.0
        total += max(0, self.passes - self.cur_pass) * cur
        for idx in range(self.cur_idx + 1, len(self.labels)):
            est = self._per_pass_est(self.labels[idx])
            if est is None:
                known, est = False, 0.0
            total += self.passes * est
        remaining_moves = (len(self.labels) - 1 - self.cur_idx) + (1 if self.final_move else 0)
        total += max(0, remaining_moves) * self._move_est()
        return total, known

    def per_pass_means(self):
        out = {}
        for label in self.labels:
            vals = self.per_pass[label]
            if len(vals) >= 2:
                out[label] = sum(vals[1:]) / len(vals[1:])
            elif vals:
                out[label] = vals[0]
        return out

    def move_mean(self):
        return (sum(self.moves) / len(self.moves)) if self.moves else None

    # -- output -------------------------------------------------------------
    def preview(self):
        total = 0.0
        for label in self.labels:
            pp = self.warm.get(label)
            if pp is None:
                return
            total += self.passes * pp
        moves = len(self.labels) + (1 if self.final_move else 0)
        total += moves * self._move_est()
        self.emit("[eta] estimated total ~%s (%d passes/station, from this set's last armed run)"
                  % (_fmt_dur(total), self.passes))

    def _maybe_emit(self, force):
        now = time.time()
        if not force and (now - self._last_emit) < ETA_LOG_INTERVAL_S:
            return
        self._last_emit = now
        elapsed = now - (self.run_t0 or now)
        remaining, known = self._remaining()
        done = sum(len(v) for v in self.per_pass.values())
        total_passes = self.passes * len(self.labels)
        label = self.labels[self.cur_idx]
        if known:
            tail = "remaining ~%s | total ~%s" % (_fmt_dur(remaining), _fmt_dur(elapsed + remaining))
        else:
            tail = "remaining estimating..."
        self.emit("[eta] elapsed %s | %s (%d/%d) pass %d/%d | %d/%d passes | %s"
                  % (_fmt_dur(elapsed), label, self.cur_idx + 1, len(self.labels),
                     self.cur_pass, self.passes, done, total_passes, tail))

    def finish(self):
        elapsed = time.time() - (self.run_t0 or time.time())
        self.emit("[eta] done | total elapsed %s" % _fmt_dur(elapsed))


# --------------------------------------------------------------------- planning
def load_plan(set_dir: Path, positions_path: Path):
    if not positions_path.is_file():
        raise SystemExit("No taught positions at %s -- run `optiscan.py jog` first." % positions_path)
    data = json.loads(positions_path.read_text(encoding="utf-8"))
    stations = data.get("stations", {})
    jobs_dir = set_dir / "WinLaseJobs"
    plan = []
    for label in STATION_ORDER:
        if label not in stations:
            raise SystemExit("Position %s missing from %s; teach all four." % (label, positions_path))
        wlj = jobs_dir / ("%s_%s.wlj" % (set_dir.name, label))
        if not wlj.is_file():
            raise SystemExit("Job not found: %s -- run winlase_build_jobs.py for this set." % wlj)
        plan.append((label, stations[label], wlj))
    return plan


def load_passes(csv_path: Path, set_name: str, default: int):
    """Mark passes per station for a set, from a CSV of `set,passes` rows.

    Exact set-folder match wins; else a 'default' row; else `default`. Blank lines,
    '#' comments, and a 'set,passes' header are ignored. Returns (passes, source).
    """
    table = {}
    if csv_path.is_file():
        with csv_path.open(newline="", encoding="utf-8") as stream:
            for row in csv.reader(stream):
                if len(row) < 2 or not row[0].strip() or row[0].lstrip().startswith("#"):
                    continue
                key, value = row[0].strip(), row[1].strip()
                if key.lower() in ("set", "name"):
                    continue
                try:
                    table[key] = int(value)
                except ValueError:
                    pass
    if set_name in table:
        return table[set_name], "%s in %s" % (set_name, csv_path.name)
    if "default" in table:
        return table["default"], "default in %s" % csv_path.name
    return default, "built-in default (%d)" % default


def print_plan(set_dir: Path, plan, passes: int, focus: bool, armed: bool) -> None:
    print("\nDicing plan for %s   [%s, %d passes/station%s]" % (
        set_dir.name, "ARMED - LASER LIVE" if armed else "SIMULATE - no laser",
        passes, ", focus on" if focus else ""))
    for label, pos, wlj in plan:
        z = ("  Z=%d" % pos["z"]) if (focus and "z" in pos) else ""
        print("  %s  ->  X=%-8d Y=%-8d%s   mark %s" % (
            label, pos["x"], pos["y"], z, wlj.name))
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

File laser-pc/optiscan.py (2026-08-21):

"""Prior OptiScan III / ProScan III stage driver + interactive teach tool.

This is the motion half of the one-button dicing automation: the OptiScan III
moves the wafer (on the fixed jig) under the fixed galvo field, so stage position
i lines up with WinLase job i. This module talks to the controller over its serial
port and gives you a safe way to (1) confirm comms, and (2) jog to and record the
four station positions the dicing script will replay.

NO LASER, NO WINLASE here -- this only moves the stage and reads it back. Bring the
laser in only after the taught positions are verified.

Command set (verified against the Prior OptiScan III manual v1.3 and the ProScan III
manual, which share the command structure). 9600 baud 8-N-1, each command ends in a
carriage return; the controller answers on one line (multi-line replies end in END):
    G,x,y[,z]   absolute move (microns; Z in 100 nm steps)      -> R
    GR,x,y[,z]  relative move                                   -> R
    GX,x GY,y GZ,z  single-axis absolute                        -> R
    PS / P,x,y,z   report / set stage position (microns)
    PZ / PZ,z      report / set focus position
    $           status: 0 = idle, nonzero = an axis is moving
    I           controlled stop (empties the queue)  K  hard stop
    M           move stage + focus to 0,0,0
    SIS         set index: DRIVES TO THE HARD LIMITS, then zeroes  (install-only)
    RIS         restore index: also drives to the limits
    COMP,0      Standard mode (recommended): R returns immediately, poll $

Runs on Python 3.8, no network. Serial goes through pyserial if present, else
pywin32 (win32file); one of those must be installed on the laser PC.

    python laser-pc/optiscan.py info                 # comms + who's connected + position
    python laser-pc/optiscan.py jog                  # interactive jog; record P1..P4
    python laser-pc/optiscan.py goto --x 25400 --y -25400
    python laser-pc/optiscan.py home                 # M -> 0,0,0 (asks first)

Safety: `goto`/`home` ask before moving. Nothing homes to the limits unless you run
`index`/`restore` explicitly -- on this rig a drive-to-limits could crash the jig or
the lens, so treat those as deliberate, watched operations.
"""

from __future__ import annotations

import argparse
import json
import sys
import time
from pathlib import Path

DEFAULT_PORT = "COM5"
BAUD = 9600
CR = b"\r"
MOVE_TIMEOUT_S = 120.0   # generous: the stage is slow, and a full-travel move must not time out
RIS_TIMEOUT_S = 180.0    # RIS drives full-travel to the hard limits and back -- allow extra
POLL_S = 0.05
STATION_KEYS = ("P1", "P2", "P3", "P4")

# ES111 stage travel is 126 mm x 76 mm, but after the 2026-08 re-datum the usable coordinate
# frame is ASYMMETRIC: X runs positive (bottom corner 16236 up to the top-right hard stop
# 143529); Y runs negative from 0 down to a -38140 FLOOR -- NOT the -57210 hard stop: the
# stage hits a PIPE at the back past -38140, so the guard stops there (protects the hardware,
# improves alignment). The coarse guard refuses a target outside this envelope before it
# reaches the controller; dice_wafer's REACHABLE_UM shares the same -Y floor, and the hardware
# limit switches are the +X/+Y backstop. (The old symmetric +/-126000 x +/-76000 guard wrongly
# rejected valid +X targets past 126000 um in the new frame.)
STAGE_X_MIN_UM, STAGE_X_MAX_UM = 0, 145_000
STAGE_Y_MIN_UM, STAGE_Y_MAX_UM = -38_140, 1_000
# After a move, PS must land within this of the target or we raise -- a micron-level
# placement gate before anything (e.g. a laser mark) trusts the position. The stage
# reports whole-micron position and lands on the commanded coordinate, so this is
# tight on purpose. If a good move ever trips it, the error prints the actual offset
# -- loosen only to what the stage genuinely repeats.
POSITION_TOLERANCE_UM = 1
# Ceiling for the interactive jog step, well under full travel.
MAX_JOG_STEP_UM = 20_000

# Motion profile applied on every connect (hardcoded per request; Prior OptiScan III SMS/SAS
# commands): SMS = stage X/Y max speed (range 1-100), SAS = stage acceleration (range 4-100).
# SMS 75 = 75% of max ("750" rescaled from the ProScan 1-1000 range to the OptiScan's 1-100);
# SAS 52 = middle of 4-100. Gentler than full speed -- the stage runs healthier here. The
# OptiScan III has NO S-curve (SCS) command, so jerk is not separately tunable. Each command is
# best-effort with a read-back on connect: a rejected/out-of-range value is warned, never fatal.
MOTION_PROFILE = (("SMS", 75), ("SAS", 52))


# --------------------------------------------------------------------------- serial
class _Serial:
    """Minimal CR-terminated serial transport: pyserial first, else pywin32."""

    def __init__(self, port: str, baud: int, read_timeout_s: float = 2.0):
        self.backend = None
        try:
            import serial  # pyserial
            self._ser = serial.Serial(port, baud, timeout=read_timeout_s,
                                      bytesize=8, parity="N", stopbits=1)
            self.backend = "pyserial"
        except ImportError:
            self._open_win32(port, baud, read_timeout_s)
            self.backend = "pywin32"

    def _open_win32(self, port: str, baud: int, read_timeout_s: float) -> None:
        try:
            import win32file
            import win32con
        except ImportError as exc:
            raise SystemExit(
                "Need pyserial or pywin32 to open the serial port, and neither is "
                "installed. On an offline PC, copy a matching wheel over and "
                "`pip install pyserial` (preferred)."
            ) from exc
        self._win32file = win32file
        name = port if port.upper().startswith("\\\\.\\") else r"\\.\%s" % port
        self._h = win32file.CreateFile(
            name, win32con.GENERIC_READ | win32con.GENERIC_WRITE, 0, None,
            win32con.OPEN_EXISTING, 0, None)
        dcb = win32file.GetCommState(self._h)
        dcb.BaudRate, dcb.ByteSize, dcb.Parity, dcb.StopBits = (
            baud, 8, win32file.NOPARITY, win32file.ONESTOPBIT)
        win32file.SetCommState(self._h, dcb)
        ms = int(read_timeout_s * 1000)
        # (interval, read-mult, read-const, write-mult, write-const)
        win32file.SetCommTimeouts(self._h, (ms, 0, ms, 0, 1000))

    def write(self, data: bytes) -> None:
        if self.backend == "pyserial":
            self._ser.write(data)
        else:
            self._win32file.WriteFile(self._h, data)

    def reset_input(self) -> None:
        """Discard any unread bytes so the next reply is read fresh.
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

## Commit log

2026-08-08 Initial commit: UV laser wafer singulation toolchain
    Geometry generation, four-window slicing, and jig generation for singulating
    100 mm wafers on a UV laser whose field is smaller than the wafer.
    - python/ KLayout macros: master generation, four-window splitter, center pass
    - tools/ reproducible build, XOR validation, station table, figure generation
    - fusion/ jig generator scripts plus exported CAD and print files
    - output/ three generated job sets, current one validated
    Position labels name the jig station: DXF11 is the top-left jig position, which
    exposes the wafer's bottom-right quadrant, since indexing the jig moves the
    wafer and inverts both axes.
    The splitter enforces its win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
    [080526_HorizDicev2.dxf, 080526_HorizDicev2_P1_right_top.dxf, 080526_HorizDicev2_P2_left_top.dxf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]
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2026-08-08 Replace the slicer UI with PySide6 + QML, add per-station alignment offsets
    The Tkinter front end was rejected on appearance, so the UI is now PySide6 + QML
    using Qt's own FluentWinUI3 style pinned to dark. Same layout, native Windows 11
    controls.
    Preview has two views, both computed by calling the splitter's own clip, layer and
    anchor functions so what is drawn cannot drift from what a run writes:
    - Wafer: the source with the four windows over it, the seam cross, and the wafer
    outline and edge bead as a guide. Station labels sit in the four outer corners,
    the only large empty areas once a round wafer is covered by square windows.
    - Sliced jobs: the four outputs as the laser sees them,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
    [100mm_wafer_10x30mm_Horizontal_master_window_manifest.csv, 100mm_wafer_10x30mm_Vertical_master_window_manifest.csv]
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2026-08-08 Remove the old-jig splitter profile, and the regenerated four-pin jig meshes
    split_klayout_four_windows_old_jig_test.py existed only to compensate the original
    printed four-position jig, with a hardcoded (-3.982, +1.678) mm window-pattern
    offset on a 60 mm field. That jig is retired, so on the pin-grid jig those offsets
    are simply wrong and the file is a splitter that silently misplaces geometry by
    4 mm. It is recoverable from history if the two archived old-jig sets ever need
    rebuilding; the five documents that referenced it now say so.
    There is now exactly one splitter.
    Also picks up the Fusion exports for the four-pin plates with pickup tabs.
    Verified straight from the binary STL vertic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
    [pin_grid_center_wafer_jig.f3d, pin_grid_center_wafer_jig.step, pin_grid_center_wafer_jig.stl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]
2026-08-08 Expose the cut overlap in the slicer UI
    Now that the window size is derived from the pitch and the stitch rather than
    pinned to the field, the overlap is safe to tune from the UI: the field has 3.2 mm
    of headroom above what a 200 um stitch needs.
    Sits at the top of the alignment panel with the ceiling shown beside it, read from
    the splitter so the hint cannot drift. It flows into the live preview, into the
    --stitch argument on a real run, and into saved datasets. Zero all restores the
    splitter's default rather than clearing it to nothing.
    Verified against the splitter: 200 um gives a 51 mm window, 1200 gives 52 mm,
    3200 gives 54 mm exactly filling the field, and 4000 is refused with the me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
2026-08-10 Loosen the pin and datum fits, add opposed tape gaps, check grid alignment
    The 0.100 mm secondary-flat datum was interfering with wafers that are perfectly
    in spec. A standard secondary flat is 18.000 +/- 2.000 mm, and a short flat cuts
    a shallower chord, so it sits further out: at 16.000 mm it is 0.173 mm proud of
    nominal, against 0.100 mm of relief. That is what forced the sanding. It is now
    0.300 mm, which clears the whole band, and the pins drop from 4.700 to 4.650 mm.
    The pin change spends alignment budget, so the arithmetic is recorded next to it:
    0.110 mm of radial play plus 0.041 mm from the rotation it allows over the
    71.842 mm pin circle is 0.151 mm, inside the 0.200 mm stitch ove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
    [pin_grid_center_wafer_jig.f3d, pin_grid_center_wafer_jig.step, pin_grid_center_wafer_jig.stl]
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2026-08-10 Add a witness-mark test pattern and an overlay figure for it
    Before dicing a wafer, expose sixteen 5 mm marks instead: four around the
    outermost 10 x 30 cell in each quadrant, each lying on one of that cell's
    boundary lines and centred on that edge's midpoint. The chosen cells are
    (+/-10, +/-30), because the (+/-40, 0) pair sit further out but straddle y = 0
    and so belong to no single station. Each cell falls wholly inside one field, so
    a station file carries exactly one cell's four marks and nothing crosses a seam.
    Measuring a printed mark against its nominal coordinate reads that station's
    placement error directly.
    The generator writes the same two filenames the production masters use, so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
    [100mm_wafer_10x30mm_Horizontal_master.dxf, 100mm_wafer_10x30mm_Horizontal_master_window_manifest.csv, 100mm_wafer_10x30mm_Vertical_master.dxf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]
2026-08-10 Put the witness marks across the field seams, not on cell boundaries
    The first version marked the boundaries of one cell per quadrant, which tests
    where a station places geometry but never exercises the thing that actually
    fails: whether two stations meet. These marks straddle the seams instead. Each
    is a 5 mm line perpendicular to its seam, so one station draws the half on its
    side and the neighbour draws the other, and a lateral error between them shows
    up as a step at the join whose size is the error.
    The seams do not fall on cell boundaries. Cut lines sit at x = +/-5, +/-15, ...
    and y = +/-15, +/-45, so x = 0 and y = 0 pass through the middle of a cell. The
    marks are centred on the oute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
    [100mm_wafer_10x30mm_Horizontal_master.dxf, 100mm_wafer_10x30mm_Horizontal_master_window_manifest.csv, 100mm_wafer_10x30mm_Vertical_master.dxf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]
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2026-08-12 Rework the jig: pressed steel dowels, tight-box plate, flat-only nest
    Replace the four printed locating pins with 3/16" steel dowels pressed into
    corner bosses with press-fit through-bores. Cut each dowel to 13 mm (8 mm bore
    engagement + 5 mm protrusion) so it matches the v2 pins' 5 mm reach into the
    table holes.
    Shrink the platform to a computed tight bounding box (123.5 x 116.6 mm), not
    centered on the nest: the corner bosses sit flush to the left and rear edges and
    merge into the perimeter bar. Reduce the engraving to a single "DESIGNED BY:
    RYAN SCOTT" credit at 2.5 mm.
    Retune the nest to locate the wafer purely on its two flats for maximum
    repeatability: primary and secondary flat clea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
    [pin_grid_wafer_jig.f3d, pin_grid_wafer_jig.step, pin_grid_wafer_jig.stl]
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2026-08-13 Aligner jig: spider reshape, 9:30 X-pin datum, maker mark; rename to Aligner*
    - Rename fusion/FusionPinGridJig -> fusion/AlignerPLA and FusionPinGridJigSLA -> AlignerSLA (matches the 081326_Aligner* print names).
    - Base reshaped to a hub over the nest plus four 15 mm arms to r10 dowel bosses; rectangular corners removed and outer corners filleted; pickup tabs deleted.
    - Wafer X set by a single 8 mm truncated-half-disc pin at 9:30 (references the OD); primary flat still sets Y + rotation; secondary flat unused, so one nest fits any SEMI flat type and flipped wafers. Arc retainer opened to 0.6 mm.
    - Removed floor text; added a RYAN SCOTT maker mark along the top-left arm.
    - README rewritten fo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
    [081326_AlignerPLA.stl, 081326_AlignerSLA.stl, pin_grid_wafer_jig.f3d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]
2026-08-13 Remove obsolete FusionSingleJig fixture
    Superseded by the four-dowel Aligner jig.
    [single_jig_wafer_indexer.f3d, single_jig_wafer_indexer.step]
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2026-08-13 AlignerAl: machined-aluminum wafer jig (milled pocket nest)
    New fusion/AlignerAL variant, derived from AlignerSLA but reworked for
    machining from a 7 mm aluminum plate:
    - Recessed nest: the wafer sits in a 2 mm milled pocket (5 mm floor
    remains), not on raised walls.
    - Located by the primary-flat front wall (Y + rotation) plus a square
    X-datum block whose R1 corner is tangent to the wafer OD at 9:30 --
    the same contact point as the SLA locating pin.
    - Plate outline auto-fits the features + 5 mm/side (a rectangle, not a
    fixed square), so no material is wasted.
    - 3/16 in reamed dowel bores; front-right pocket corner left solid so
    that bore stays in full metal; left wall runs flush wi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
    [081326_AlignerAl.f3d, 081326_AlignerAl.step]
2026-08-14 Recal 081326: global residual offset + per-station stitch nudges
    - split_klayout.py: set GLOBAL offset to +185.3 X / +438.0 Y um, the residual on
    top of the jig's baked NEST_CALIBRATION from the flat-standoff line-to-flat
    shortfall (-0.185 minor X / -0.438 major Y mm).
    - Bake per-station WINDOW_OFFSETS_UM differential nudges (sum to 0,0) from the
    seam-step measurements to close each X/Y stitch.
    - Update CALIBRATION_AND_SLIDING_NEST_NOTES.md and alignment_flat_standoffs.xlsx
    with the measurements behind the recal. Offsets are provisional pending the
    next cut (verify standoffs grow toward nominal; flip signs if they shrink).
    [alignment_flat_standoffs.xlsx]
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2026-08-14 Dicing automation: file-driven passes, 400 mm/s, safety hardening, USB package
    - optiscan.py (Prior OptiScan III stage driver): flush-before-command fix for the
    read desync; machine-readable error detection (ERROR,0) + expected 'R' ack on
    moves so a rejected move can't read as success; software soft-limits + capped jog
    step; post-move position verify; home via stage-only G,0,0; positions default
    resolved next to the script.
    - dice_wafer.py (one-command dicer): mark passes per set from dice_passes.csv
    (alignment sets = 50, else 175), --passes override; --home-after gated on a clean
    run (no motion after an abort); positions default next to the script.
    - winlase_build_jobs.py: bake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
    [dice_passes.csv]
2026-08-14 Reset calibration to zero for the stage method; force 400 mm/s (speed-only)
    - split_klayout.py: GLOBAL_*_OFFSET_UM and WINDOW_OFFSETS_UM reset to 0. The
    stage-based method starts from fresh calibration; the pinned-jig recal no longer
    applies. Regenerated the 081326 AlignmentTest v1/v2/v3 sets with zero offsets
    (XOR-validated, split logs confirm 0/0 global and per-station).
    - winlase_build_jobs.py: set mark speed to 400 mm/s by writing ONLY Profile 0's speed
    field (the WinLase default profile is 1000 mm/s), then read the profile back and
    verify laser power and frequency are unchanged, aborting the build otherwise. It
    never writes power or frequency.
    - README: input is the sliced S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
    [100mm_wafer_10x30mm_Horizontal_master_window_manifest.csv, 100mm_wafer_10x30mm_Vertical_master_window_manifest.csv, Horizontal.dxf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]
2026-08-14 Add Tkinter launcher UI (Win7); UI-safe abort + friendly pywin32 error
    - dice_ui.py: stdlib Tkinter launcher (Win7/Py3.8, zero install). Set-folder dropdown
    + Info/Home/Jog/Build/Dry-run/DICE buttons + STOP; each subprocesses the existing CLI
    and streams its output, so the audited safety logic runs unchanged. DICE requires an
    explicit confirm dialog; STOP writes a stop-flag for a controlled stop.
    - run_ui.bat: double-click launcher (venv pythonw).
    - dice_wafer.py: --yes (skip the console 'type DICE' prompt; the UI confirms) and
    --stop-flag PATH (controlled-stop signal from the UI); the countdown honors it too.
    - dice_wafer.py + winlase_build_jobs.py: on a missing pywin32, exit with a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
    [dice_ui.py, dice_wafer.py, winlase_build_jobs.py]
2026-08-14 Dicing: laser-profile safety gate, param readout, ephemeral jobs, UI passes
    Laser safety:
    - Enforce the confirmed WinLase profile (power 100 %, freq 30 kHz, mark
    speed 400 mm/s) as an absolute gate. winlase_build_jobs refuses to SAVE a
    job whose profile does not match; dice_wafer verifies every job before any
    stage motion or firing (and re-checks at mark time). Neither ever writes
    laser power or frequency -- read-and-verify only.
    - Fix the param readout: drop the broken GetDefaultProfile call and report
    the profile read back from the job via GetObjProfile.
    dice_wafer:
    - Delete the .wlj files after a clean armed run (regenerate each run, no
    clutter); --keep-jobs opts out. Dry run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
    [dice_ui.py, dice_wafer.py, optiscan.py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]
2026-08-14 Dicing: wait for WinLase idle after every pass (fix P2 busy-timeout)
    MarkAllObj is asynchronous, so the old loop closed a job and loaded the next
    while the last pass was still marking -- WinLase stayed "busy" and the next
    station timed out before pass 1. Now mark_job waits for idle before starting a
    job and after every pass, so a job fully drains before it is closed. Waits are
    abort-aware (STOP works mid-mark) with a 120 s timeout. A busy/stage timeout
    now aborts cleanly (rc=1) instead of a raw traceback.
    [dice_wafer.py]
2026-08-14 Calibration: stage-method global + per-station offsets, 081326/081426 seam tests
    Slicer (split_klayout.py) stage-method calibration, iterated against cut alignment
    lines (line-to-flat, both flats). Final state:
    GLOBAL_X_OFFSET_UM = 3738.0
    GLOBAL_Y_OFFSET_UM = -740.0
    WINDOW_OFFSETS_UM = P1 (-40,-20), P2 (-40,0), P3/P4 (0,0)
    X converged from a ~3.58 mm zero-offset error into a ~+/-70 um cut-to-cut band
    (residuals -3578 -> -238 -> +92 -> +52 -> -68 um across v1..v5); Y is spot-on
    (major-flat line lands on design two cuts running); the P1/P2 bottom-tile nudges
    close the y=0 seam step (improving, sub-unity per nudge). Derivation for each
    iteration is in the split_klayout.py comments.
    Reg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
    [100mm_wafer_10x30mm_Horizontal_master.dxf, 100mm_wafer_10x30mm_Horizontal_master_window_manifest.csv, 100mm_wafer_10x30mm_Vertical_master.dxf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]
2026-08-15 Reorg apps into laser-pc/ + slicing/; zero offsets and regen v1-v6
    Repository split into two application folders (old tools/ + python/ removed):
    - laser-pc/: on-machine dicing app (OptiScan stage driver, WinLase job builder,
    one-button dicer, Tk UI) for the offline laser PC.
    - slicing/: DXF master generation, the four-window splitter, build/validate, and
    the PySide6/QML preview GUI. Intra-slicing paths resolve via Path(__file__).parent
    so the scripts still run from the repo root unchanged.
    Command examples and folder docs updated across README, DOCUMENTATION,
    OPERATING_PROCEDURE, the calibration notes, and the fusion comments.
    Calibration: zeroed GLOBAL_X/Y_OFFSET_UM and WINDOW_OFFSET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
    [080526_HorizDicev2_P1_right_top.dxf, 080526_HorizDicev2_P2_left_top.dxf, 080526_HorizDicev2_P3_right_bottom.dxf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]
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2026-08-15 Calibration: back-side reconciled global -3447/+460 + per-tile; log in notes
    Recalibrated on the inverted (back-side) wafer. Calibrate X on the round edge and Y
    on the major flat: the minor flat mis-references ~370 um (flat 18.4 mm) and drove the
    X global the wrong way, so X reverts from -3854/-4452 to -3447 (round edge verified:
    right mark +6 um from nominal at -3447). Y = +460 (major flat dead-on). Per-tile seam
    nudges: P1(-117.5,-62.5) P2(-105,-15) P3(0,-10) P4(0,-10).
    v4 regenerated at these values (validates zero-XOR, in-field). v5/v6 remain at the
    earlier -3854/+450 pending a rebuild. Reconciliation and current values logged in
    CALIBRATION_AND_SLIDING_NEST_NOTES.md.
    [100mm_wafer_10x30mm_Horizontal_master_window_manifest.csv, 100mm_wafer_10x30mm_Vertical_master_window_manifest.csv, Horizontal.dxf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]
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2026-08-15 slicing+dice: edge-bead H/V fix, P1 up 15um, ETA cache hardening
    - build_pin_grid_set (build_combined): split the cut network into H/V BEFORE the edge-bead
    clip, so the exact-zero lossless gate validates the pristine split. Clipping the streets
    to the wafer arc first left a ~0.02 um^2 rounding sliver that tripped the gate -- why
    --edge-bead 1.0 on 081126_2Ford2Meta_P100 (layer 5/0) failed while the 4Ford at edge-bead
    0 passed. The bead is now applied to each orientation after the split. Verified:
    081426_2Ford2Meta_P100 builds and validates (xor 0, ALL CHECKS PASS).
    - split_klayout: P1 window offset up 15 um (-62.5 -> -47.5).
    - dice_wafer: harden the ETA cache (flagged by an adversa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
    [dice_wafer.py]
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2026-08-20 laser-pc: add RIS re-datum cadence (--redatum off|row|move)
    OptiScan.redatum() restores the index (RIS) before a move so an open-loop run can re-reference the datum and stop accumulating drift; dice_wafer --redatum move re-datums before every station, row before the first only (dicing is a flat P1..P4 list, no rows), default off. A failed RIS is a controlled stop -- never fire on an unverified datum. Mirrors the exposure repo. Opt-in and only as accurate as the stage's limit-switch repeatability (qualify first).
    [dice_wafer.py, optiscan.py]
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2026-08-20 dicing: Home->window center, Extract->+X/+Y corner; station reachability preflight; tol 1um
    dice_ui Home now parks at the usable-window center and Extract at its +X/+Y corner (hardcoded REACHABLE_UM, since dicing has no calibration file; kept in sync with exposure). dice_wafer adds a pre-flight that REFUSES to run if any TAUGHT station is outside the window -- catches stale prior-datum positions (old P1 negative X) that otherwise fail silently as 'X won't move', with a 're-teach P1-P4' message. Position tolerance 3um -> 1um.
    [dice_ui.py, dice_wafer.py, optiscan.py]
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2026-08-20 fix: read --combined DXF sources as mm (dxf_unit=1000); regenerate 082026 alignment tests
    build_combined() read the --combined DXF with layout.read() and no dxf_unit, so KLayout's
    default (1 DXF unit = 1 um, confirmed) interpreted the millimeter masters 1000x too small.
    The radial marks (radius ~41 mm) collapsed to ~0.041 mm at the wafer origin, so (a) every
    mark was ~1000x undersized and (b) all four fell inside the +/-0.2 mm stitch-overlap band
    and got clipped into EVERY station -- the "too small" + "all four markers in every file"
    report. DXF sources now set dxf_unit=1000 (matching split_klayout.py INPUT_DXF_UNIT_UM);
    GDS/OAS still carry their own units and read as-is.
    Regenerated 082026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
    [082026_AlignmentTest_v3_Horizontal_master.dxf, 082026_AlignmentTest_v3_Horizontal_master_window_manifest.csv, 082026_AlignmentTest_v3_Vertical_master_window_ma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]
2026-08-21 slicer: new-jig global offset +4850/-3207 um; regenerate v5
    First calibration for the +X-major / -Y-minor jig, from the v6 radial seam test (major(+X)
    15.35 vs 10.500 expected, minor(-Y) 9.19 vs 12.397). +X = toward the +X major flat; the -Y
    term is negative because this jig's design->stage mapping inverts Y (confirmed on the wafer).
    v5 rebuilt with the offset (every station shifted +4.850 X / -3.207 Y, verified). Per-station
    WINDOW_OFFSETS still zero -- the tile-to-tile tuning is deferred pending the P1-P4 rework.
    [100mm_wafer_10x30mm_Horizontal_master_window_manifest.csv, 100mm_wafer_10x30mm_Vertical_master_window_manifest.csv, Horizontal.dxf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]
2026-08-21 stage: -Y pipe floor -38140, move->RIS->re-seat datum order, gentle OptiScan motion profile
    - -Y floor -38140 um (was -52210): the stage hits a pipe at the back past that. Applied to
    REACHABLE_UM (dice_wafer + dice_ui) and the optiscan _check_target guard, which is also
    rewritten to the real asymmetric envelope X[0,145000] Y[-38140,1000] (the old symmetric
    +/-126000/+/-76000 guard wrongly rejected valid +X targets past 126000 in the re-datum frame).
    - Re-datum order reversed: move to the target FIRST, then RIS, then re-command the target. RIS
    returns to its pre-RIS position (the target), re-references the datum there, so the final goto
    is a short, consistent datum->target correctio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
    [dice_ui.py, dice_wafer.py, optiscan.py]
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2026-08-21 slicer: reset baked offsets to 0; rebuild today's alignment sets full-range for the +Y nest
    The v6-derived +X-jig global offset (+4850/-3207) is retired -- it doesn't apply to the +Y-flat
    nest, and the full-range decoupled dicing calibrates via the taught stations, not a baked DXF
    offset (baking into a full-field job overflows the galvo). GLOBAL_*_OFFSET_UM back to 0 (per-tile
    WINDOW_OFFSETS already 0); the +X value is kept in git history.
    Rebuilt 082026_AlignmentTest_v3/v4/v5/v6 (radial, mark-from-flat 6000/7500/9000/10500) with the
    +Y-nest full-range tiling: --window-center-y 18000 (X stays 25400), --field 66000, --clip-mode
    full_window, --global 0. Verified: coverage dropped 0, no galvo-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
    [100mm_wafer_10x30mm_Horizontal_master_window_manifest.csv, 100mm_wafer_10x30mm_Vertical_master_window_manifest.csv, Horizontal.dxf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]
2026-08-21 dice: bidirectional fill (style 2) + 1000 mm/s mark speed
    - SetObjFill style 0 (parallel/unidirectional) -> 2 (bidirectional): the galvo scans alternate
    directions with no flyback between fill lines, so each pass is faster. Slightly looser line
    registration, fine for kerf depth.
    - Mark speed 400 -> 1000 mm/s (the WinLase default). Kept the build value (winlase_build_jobs
    MARK_SPEED_MM_S) and the arm-time gate (dice_wafer EXPECTED_MARK_SPEED_MM_S) in sync, or the
    armed run's laser-profile check would refuse the job.
    Both save travel/mark time; expect shallower cut per pass at 1000 mm/s -- bump passes in
    dice_passes.csv if needed. The build can't verify fill STYLE, so eyeball the firs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
    [dice_wafer.py, winlase_build_jobs.py]
2026-08-21 dice: 100 mm/s + parallel fill; dialed-in 0-deg-shimmed P1-P4
    - Mark speed 1000 -> 100 mm/s (slow/deep cut so fewer passes are needed). Build value
    (winlase_build_jobs MARK_SPEED_MM_S) and arm-gate (dice_wafer EXPECTED_MARK_SPEED_MM_S) kept in sync.
    - Fill reverted from bidirectional (style 2) back to parallel/unidirectional (style 0): at 100 mm/s,
    clean lines beat the small bidirectional line-registration error.
    - optiscan_positions.json -> the dialed-in baseline: 0-deg nest shimmed ~9.5 mm forward, reference
    (84433, -18830), P1-P4 = ref +/- (25400, 18000) = (59033/109833, -36830/-830). Two v6 iterations
    centered the pattern to <0.3 mm; on-wafer placement repeats sub-micron so that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
    [dice_wafer.py, winlase_build_jobs.py]
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2026-08-21 winlase: fill angle follows the cut line; tolerate empty orientation DXFs
    Diagonal alignment marks (082126 radial-45) broke the builder two ways:
    1. Each station has a mark in only one master, so the other orientation's DXF is empty ->
    dxf_bounds_mm raised "No LWPOLYLINE vertices". Now an empty orientation is skipped with a
    note instead of crashing (the mark lives in the other master). Object-count check relaxed:
    warn only when a job holds zero objects.
    2. Fill angle was fixed per master (H=0, V=90), so a diagonal mark got cross-hatched instead
    of cut along its length. New cut_angle_deg() reads the longest edge per LWPOLYLINE and sets
    the fill to that angle, folded into WinLas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
    [winlase_build_jobs.py]
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2026-08-21 cleanup: docs + dead code for the N-angle pipeline / definitive calibration
    Docs synced to the current state (N-angle per-pass-angle files named by angle, definitive
    taught calibration (84355,-19056), zero baked slicer/window offsets, edge-datum jig, OptiScan,
    scripts under slicing/):
    - DOCUMENTATION.md: jig table -> edge-datum jigs (drop dead FusionPinGridJig/FusionSingleJig
    links); pipeline outputs -> one DXF per pass angle.
    - CALIBRATION_AND_SLIDING_NEST_NOTES.md: mark the baked GLOBAL/WINDOW offsets superseded (reset
    to 0; taught-station reference is definitive); bump the date.
    - OPERATING_PROCEDURE.md: stage-indexed flow (jig pinned, dice_wafer steps P1-P4), per-pass fill
    angle fr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
    [winlase_build_jobs.py]
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
